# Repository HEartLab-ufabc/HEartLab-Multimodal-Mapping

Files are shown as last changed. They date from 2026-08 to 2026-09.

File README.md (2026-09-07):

# An Open-Source Platform for Multimodal Electrical and Optical Mapping of Ex Vivo Hearts

**A modular research platform for synchronized optical, contact-electrical, and torso-tank mapping of ex vivo perfused hearts.**

> **Repository status:** Active development. Documentation, design files, protocols, and software are being prepared for the first archived release accompanying the associated *Scientific Reports* manuscript.

## Overview

This repository contains the hardware documentation, embedded firmware, experimental-control software, CAD files, representative experimental protocols, and 3D reconstruction tools associated with the HEartLab multimodal mapping platform for ex vivo cardiac electrophysiology.

The platform integrates complementary experimental modalities within a common workflow:

- optical mapping;
- contact electrical mapping using multi-electrode arrays (MEAs);
- torso-tank electrical mapping;
- electrical stimulation;
- physiological monitoring;
- hardware synchronization;
- experiment control and event logging;
- rotational image acquisition and experiment-specific 3D reconstruction.

The system is modular rather than tied to one preparation. Perfusion interfaces, mechanical supports, electrode arrangements, optical geometry, and selected experimental procedures can be adapted according to preparation size, scientific objective, and available equipment.

---

## Experimental configurations

### Small-heart whole-organ configuration

Validated in Langendorff-perfused rabbit hearts. Depending on the experiment, the configuration supports:

- panoramic optical mapping;
- epicardial contact mapping using MEAs;
- torso-tank electrical recordings;
- programmable electrical stimulation;
- physiological monitoring;
- synchronized optical and electrical acquisition;
- experiment control and logging;
- experiment-specific 3D reconstruction.

### Large-heart whole-organ configuration

Validated in porcine and human ex vivo hearts. Depending on the experiment, the configuration supports:

- optical mapping of large cardiac surfaces;
- torso-tank electrical mapping;
- independent coronary perfusion;
- physiological monitoring;
- synchronized acquisition and stimulation;
- mechanical support adapted to larger preparations;
- experiment-specific 3D reconstruction.

### Large-heart epi-endo configuration

Developed for isolated perfused ventricular-wall preparations. Depending on the experiment, the configuration supports:

- simultaneous epicardial and endocardial optical mapping;
- paired epicardial and endocardial contact-electrical mapping;
- mirror-assisted optical access;
- coronary perfusion;
- synchronized stimulation and acquisition;
- physiological monitoring.

The configuration defines the available platform modules, while the **scientific objective determines which modules and protocols are used in a particular experiment**.

---

## Platform modules

HEartLab is organized around interoperable experimental modules:

- **Perfusion** – maintains the isolated preparation under controlled ex vivo conditions.
- **Physiological monitoring** – records perfusion flow, pressure, and temperature.
- **Optical mapping** – records voltage-sensitive fluorescence from cardiac surfaces.
- **Contact electrical mapping** – records local extracellular electrograms using MEAs.
- **Torso-tank mapping** – records cardiac potentials from electrodes surrounding the preparation in a conductive volume.
- **Electrical stimulation** – provides controlled pacing and arrhythmia-induction stimuli.
- **Hardware synchronization** – provides a common timing reference between acquisition systems.
- **Experiment control** – coordinates monitoring, stimulation, synchronization, metadata, and experimental events.
- **3D reconstruction** – combines rotational image acquisition with silhouette-based processing to obtain experiment-specific surface geometry.

---

## Repository structure

```text
HEartLab-Multimodal-Mapping/
├── README.md
├── DISCLAIMER.md
│
├── cad/
│   ├── README.md
│   ├── small_heart/
│   ├── large-heart/
│   └── epi-endo/
│
├── docs/
│   ├── getting_started.md
│   └── protocols/
│
├── firmware/
│   ├── sensors/
│   ├── gateway/
│   ├── stepper_motor_control/
│   └── synchronization_controller/
│
├── hardware/
│   ├── README.md
│   ├── BOM_overview.md
│   ├── perfusion/
│   ├── physiological_monitoring/
│   ├── optical_mapping/
│   ├── electrical_mapping/
│   ├── stimulation/
│   ├── synchronization/
│   ├── mechanical/
│   └── reconstruction_3d/
│
└── software/
    ├── README.md
    ├── experiment_control/
    ├── 3D_reconstruction_capture_labview/
    ├── 3D_reconstruction_capture_python/
    └── 3d_reconstruction_processing/
```

---

## Getting started

A high-level setup and validation workflow is provided in:

**[`docs/getting_started.md`](docs/getting_started.md)**

A typical workflow is:

1. select the experimental configuration;
2. define the scientific objective;
3. select the required platform modules and representative protocols;
4. obtain or fabricate the required hardware;
5. configure firmware and software;
6. validate each subsystem independently;
7. perform an integrated bench test;
8. document the experiment-specific configuration.

The platform does **not** require every subsystem to be used in every experiment.

---

## Experimental protocols

Representative experimental procedures are provided in:

**[`docs/protocols/`](docs/protocols/)**

These documents describe examples of HEartLab implementations rather than universal mandatory procedures. Parameters can vary according to preparation type, species or donor source, heart size, mapping modality, scientific objective, equipment, pharmacological intervention, stimulation protocol, and the applicable approved experimental protocol.

Users are responsible for confirming that concentrations, calculations, settings, and procedures are appropriate for their own experimental implementation.

---

## CAD and mechanical designs

Custom mechanical designs are provided in:

**[`cad/`](cad/)**

The CAD library is organized according to the configuration in which the components were developed:

- [`cad/small_heart/`](cad/small_heart/)
- [`cad/large-heart/`](cad/large-heart/)
- [`cad/epi-endo/`](cad/epi-endo/)

Depending on the component, files include Autodesk Inventor (`.ipt`), Autodesk Fusion (`.f3d` / `.f3z`), STEP/STP, STL, and PDF drawings.

The repository focuses on custom fabricated components. Commercial motors, bearings, pulleys, shafts, fasteners, clamps, and similar off-the-shelf parts are described in the relevant documentation rather than redistributed as proprietary CAD models.

---

## Hardware

Hardware documentation is located in:

**[`hardware/`](hardware/)**

Subsystem documentation includes:

- [`hardware/perfusion/`](hardware/perfusion/) – perfusion and fluidic hardware;
- [`hardware/physiological_monitoring/`](hardware/physiological_monitoring/) – flow, pressure, temperature, sensor nodes, and gateway hardware;
- [`hardware/optical_mapping/`](hardware/optical_mapping/) – cameras, optics, illumination, and mirror-assisted optical access;
- [`hardware/electrical_mapping/`](hardware/electrical_mapping/) – MEAs, small-heart torso-tank hardware, and large-heart tank PCB files;
- [`hardware/stimulation/`](hardware/stimulation/) – experimental constant-current stimulation hardware;
- [`hardware/synchronization/`](hardware/synchronization/) – timing and trigger-distribution hardware;
- [`hardware/mechanical/`](hardware/mechanical/) – assembly-level mechanical documentation linked to the CAD library;
- [`hardware/reconstruction_3d/`](hardware/reconstruction_3d/) – motorized rotational acquisition hardware.

A high-level component inventory is provided in [`hardware/BOM_overview.md`](hardware/BOM_overview.md).

### Large-heart tank PCB

Editable KiCad source, electrode mapping, Gerber/drill outputs, and manufacturing previews are provided under:

**[`hardware/electrical_mapping/large-heart-tank-pcb/`](hardware/electrical_mapping/large-heart-tank-pcb/)**

The large-heart tank uses six PCB faces with 15 electrode pads per face.

---

## Firmware

Embedded firmware is located in:

**[`firmware/`](firmware/)**

The current implementation includes:

- Arduino Nano-based physiological-monitoring sensor nodes;
- nRF24L01 wireless communication;
- an ESP32-S3 sensor gateway;
- a Teensy 4.1 synchronization/stimulation-control interface;
- an Arduino-controlled stepper system for rotational 3D image acquisition.

Subsystem-specific README files describe the associated interfaces and operating assumptions.

---

## Software

Software is located in:

**[`software/`](software/)**

### Experiment control

[`software/experiment_control/`](software/experiment_control/) contains the Python-based application used for experimental session organization, physiological monitoring, stimulation control, synchronization-related operations, metadata, and event logging.

### 3D image acquisition — LabVIEW / EVT

[`software/3D_reconstruction_capture_labview/`](software/3D_reconstruction_capture_labview/) contains the LabVIEW application used with the EVT camera implementation.

The acquisition workflow rotates the preparation at defined angular increments and stores the image sequence used for subsequent 3D reconstruction.

A RHYTHM-derived LabVIEW VI included in this folder retains its original third-party attribution and MIT license notice.

### 3D image acquisition — Python / Imaging Source USB

[`software/3D_reconstruction_capture_python/`](software/3D_reconstruction_capture_python/) contains the Python/OpenCV implementation used with the Imaging Source USB-camera setup.

### 3D reconstruction processing

[`software/3d_reconstruction_processing/`](software/3d_reconstruction_processing/) contains the silhouette-processing and space-carving workflow used to produce experiment-specific surface meshes.

Camera calibration is performed using [MC-Calib](https://github.com/rameau-fr/MC-Calib); its calibration procedure is not duplicated in this repository.

---

## Reproducibility and scope

The repository documents the implementation used to develop and validate the HEartLab platform. Because the platform is modular, exact equipment combinations and experimental procedures can differ among preparations.

For reproducibility, experimental records should preserve the relevant hardware configuration, firmware/software versions, acquisition settings, channel mapping, and protocol parameters used for a given dataset.

Commercial acquisition software, manufacturer drivers, SDKs, and proprietary third-party design files are not redistributed unless their licenses permit redistribution.

---

## Associated manuscript

This repository accompanies:

**Silva, V. P. et al. _An Open-Source Platform for Multimodal Electrical and Optical Mapping of Ex Vivo Hearts_.**

**Status:** manuscript under review.

---

## License

This repository uses a **multi-license structure**:

| Material | License |
|---|---|
| Original software and firmware | MIT License |
| Original hardware and CAD designs | CERN Open Hardware Licence Version 2 – Permissive |
| General documentation and experimental protocols | Creative Commons Attribution 4.0 International |
| Third-party components | Original third-party licenses |

See [`LICENSE.md`](LICENSE.md) for the complete scope and
[`THIRD_PARTY.md`](THIRD_PARTY.md) for third-party exceptions.

---

## Third-party components

Third-party software remains subject to its original license terms.

In particular, the LabVIEW reconstruction-acquisition folder contains a VI derived from the RHYTHM open-source imaging toolkit. Attribution and the applicable MIT license notice are provided in:

[`software/3D_reconstruction_capture_labview/THIRD_PARTY.md`](software/3D_reconstruction_capture_labview/THIRD_PARTY.md)

---

## Contact

For technical questions or reproducibility issues, please open a GitHub issue.

For research collaboration or questions regarding the associated manuscript, contact HEartLab at Universidade Federal do ABC (UFABC).

---

## Disclaimer

The hardware designs, firmware, software, protocols, CAD files, and documentation provided in this repository are supplied **"as is"**, without warranties or guarantees of any kind, either express or implied.

The materials are intended exclusively for experimental research involving ex vivo cardiac preparations. They have not been designed, validated, or approved as medical devices and must not be used for clinical diagnosis, treatment, patient monitoring, or direct use in humans.

Users are responsible for independently reviewing and validating hardware, software, calculations, procedures, electrical connections, experimental parameters, concentrations, and safety measures before use.

The individual researcher or institution conducting an experiment remains responsible for determining whether the platform and associated procedures are appropriate for the intended application and for ensuring compliance with applicable ethical approvals, institutional requirements, laboratory procedures, and safety regulations.

See the complete [`DISCLAIMER.md`](DISCLAIMER.md).

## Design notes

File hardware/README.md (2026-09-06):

# Hardware

This directory contains documentation and design information for the hardware used in the HEartLab multimodal ex vivo cardiac mapping platform.

The platform is modular. A particular experiment does not require every module, and some mechanical, perfusion, optical, and electrical interfaces change according to preparation size and scientific objective.

## Hardware modules

```text
hardware/
├── README.md
├── BOM_overview.md
├── perfusion/
├── physiological_monitoring/
├── optical_mapping/
├── electrical_mapping/
├── stimulation/
├── synchronization/
├── mechanical/
└── reconstruction_3d/
```

### `perfusion/`

Perfusion architecture, reservoirs, pumps, tubing, heat exchange, bubble management, flow monitoring, pressure monitoring, and cannulation interfaces.

### `physiological_monitoring/`

Sensor nodes and gateway hardware used to monitor perfusion flow, pressure, and temperature.

### `optical_mapping/`

Cameras, lenses, excitation illumination, emission filtering, mirror-assisted views, and hardware interfaces used for voltage-sensitive optical mapping.

### `electrical_mapping/`

Contact-electrical mapping and torso-tank mapping hardware, including MEAs, small-heart tank electrodes, large-heart tank PCBs, acquisition interfaces, and channel organization.

### `stimulation/`

Electrical stimulation hardware used for pacing and arrhythmia-induction protocols.

### `synchronization/`

Hardware timing interfaces used to provide a common temporal reference between optical and electrical acquisition systems.

### `mechanical/`

A guide to mechanical hardware and the corresponding CAD repository. Detailed custom mechanical designs are maintained under [`../cad/`](../cad/) rather than duplicated here.

### `reconstruction_3d/`

Motorized rotational hardware and imaging components used to acquire multi-view images for experiment-specific 3D reconstruction.

## Configuration overview

The table below summarizes the typical relationship between hardware modules and the three principal platform configurations.

| Module | Small-heart whole-organ | Large-heart whole-organ | Large-heart epi-endo |
|---|---|---|---|
| Perfusion | Aortic/Langendorff | Independent coronary perfusion | Coronary perfusion |
| Physiological monitoring | Used as required | Used as required | Used as required |
| Optical mapping | Panoramic multi-camera | Large-surface multi-camera | Dual-surface / mirror-assisted |
| Contact electrical mapping | Epicardial MEAs | Experiment dependent | Epicardial + endocardial MEAs |
| Torso-tank mapping | 60-electrode tank implementation | Six-face tank PCB implementation | Not a defining module |
| Electrical stimulation | Experiment dependent | Experiment dependent | Experiment dependent |
| Synchronization | When multimodal acquisition is used | When multimodal acquisition is used | When multimodal acquisition is used |
| 3D reconstruction hardware | Experiment dependent | Experiment dependent | Experiment dependent |

The table describes representative HEartLab implementations and should not be interpreted as a mandatory experimental sequence.

## Design philosophy

The hardware was developed around experimental functions rather than a single fixed physical arrangement.

Common design goals include:

- maintaining controlled perfusion;
- preserving optical and electrical access to the preparation;
- monitoring relevant physiological conditions;
- enabling programmable stimulation where required;
- acquiring complementary electrical and optical measurements;
- providing a common timing reference between acquisition systems;
- allowing adaptation to different preparation dimensions.

## Documentation convention

Each hardware directory contains, where applicable:

- a subsystem overview;
- representative bill of materials;
- configuration-specific notes;
- links to firmware or software;
- links to CAD files;
- fabrication/manufacturing files;
- operating notes, limitations, and compatibility information.

Commercial components are identified to support reproducibility but their proprietary design files are not redistributed.

## Important

The listed hardware corresponds to HEartLab implementations used during platform development. Exact component models, dimensions, calibration, electrical limits, and material compatibility must be independently verified before use.

See the repository-level [`DISCLAIMER.md`](../DISCLAIMER.md).

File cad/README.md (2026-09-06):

# CAD and Mechanical Design Files

This directory contains mechanical design files for custom components used in the HEartLab multimodal mapping platform.

The designs are organized according to the experimental configuration in which they were developed:

- [`small_heart/`](small_heart/) – components used with the small-heart whole-organ configuration;
- [`large-heart/`](large-heart/) – components used with the large-heart whole-organ configuration;
- [`epi-endo/`](epi-endo/) – components used with the large-heart epi-endo configuration.

The majority of the files provided here correspond to **custom components that must be fabricated or 3D printed**.

Commercial and off-the-shelf components, such as motors, bearings, pulleys, belts, shafts, fasteners, clamps, and other standard mechanical components, are identified in the corresponding documentation and assembly drawings but their proprietary CAD models are generally not redistributed in this repository.

## File formats

Where available, components are provided in several formats to facilitate both reproduction and modification.

| Format | Purpose |
|---|---|
| `.ipt` | Native Autodesk Inventor source file |
| `.f3d` | Native Autodesk Fusion design file |
| `.f3z` | Autodesk Fusion archive containing an assembly and/or externally referenced components |
| `.step` / `.stp` | Vendor-neutral CAD exchange format |
| `.stl` | Mesh file intended primarily for additive manufacturing |
| `.pdf` | Assembly drawings, dimensioned drawings, or reference documentation |

Native CAD files are provided whenever possible to preserve design history and editability. STEP files are included to improve compatibility with other CAD software, while STL files are intended primarily for fabrication of 3D-printed components.

## General fabrication notes

The supplied designs correspond to implementations used in HEartLab experiments and should be treated as reference designs rather than universal dimensions.

Mechanical components may require adaptation according to:

- preparation size;
- tank geometry;
- cannula dimensions;
- locally available bearings, shafts, motors, and pulleys;
- camera and electrode positioning;
- available fabrication methods.

Before fabrication, verify:

- model units;
- critical dimensions;
- fit between mating components;
- shaft and bearing tolerances;
- required threaded inserts or fasteners;
- intended material;
- compatibility with the experimental environment.

Components exposed to moisture, perfusate, or corrosive environments should be manufactured using materials and hardware appropriate for those conditions.

## Assemblies and off-the-shelf components

Assembly drawings may show commercial components that are not included as CAD files in this repository.

This is intentional. Their presence in an assembly is intended to document the mechanical interface and reproduce the experimental arrangement, not to redistribute manufacturer designs.

Relevant specifications for these components are listed in the corresponding README or bill of materials.

## Configuration-specific documentation

Each configuration directory contains additional information describing:

- the purpose of each custom component;
- required quantities;
- associated commercial components;
- assembly considerations;
- fabrication recommendations;
- files available for each part.

## Modification and reuse

The mechanical system is intentionally modular. Users may modify the designs to accommodate different preparations, tanks, equipment, or experimental objectives.

Any modified design should be mechanically verified before experimental use.

See the repository-level `DISCLAIMER.md` for additional information regarding validation, responsibility, and intended use.

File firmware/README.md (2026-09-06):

# Embedded Firmware

This directory contains firmware used by the embedded control, monitoring, synchronization, and motor-control subsystems of the HEartLab multimodal mapping platform.

## Directory structure

### `sensors/`

Firmware for Arduino Nano-based physiological-monitoring nodes.

### `gateway/`

Firmware for the ESP32-S3 gateway that receives physiological-monitoring data and interfaces with the experimental-control computer.

### `synchronization_controller/`

Firmware for the Teensy 4.1 timing controller used to generate and distribute experimental synchronization signals.

### `stepper_motor_control/`

Arduino firmware for the motorized rotational stage used during experiment-specific 3D reconstruction image acquisition.

The controller receives angular movement commands through the serial interface and drives a STEP/DIR stepper-motor driver.

A representative reconstruction acquisition uses approximately 100 positions over 360°, corresponding to 3.6° increments.

See:

[`stepper_motor_control/README.md`](stepper_motor_control/README.md)

## Monitoring and synchronization architecture

```text
Sensor node 1 --\
                 \
Sensor node 2 ----> wireless --> ESP32-S3 gateway --> USB --> Experiment computer
                 /
Additional ------/
nodes

Experiment computer --> timing/synchronization controller --> acquisition systems
```

Refer to the subsystem-specific README files for exact interfaces.

## Rotational image-acquisition architecture

```text
Image-acquisition software
        |
        | Serial/USB
        v
     Arduino
        |
    STEP / DIR
        v
 Stepper driver
        |
        v
 Stepper motor
        |
        v
Rotational support
```

The current LabVIEW image-acquisition implementation is designed for EVT cameras:

[`../software/3D_reconstruction_capture_labview/`](../software/3D_reconstruction_capture_labview/)

The Python/OpenCV acquisition implementation for the Imaging Source USB-camera setup is available at:

[`../software/3D_reconstruction_capture_python/`](../software/3D_reconstruction_capture_python/)

## Development environment

Controller, library, pin-assignment, communication, and upload information is provided in the subsystem-specific README files together with the corresponding source code.

## Disclaimer

Firmware in this repository is provided for experimental research and must be independently verified with the intended electronics and mechanical system before experimental use.

See the repository-level [`DISCLAIMER.md`](../DISCLAIMER.md).

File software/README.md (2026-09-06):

# Software

This directory contains software developed or used to support operation of the HEartLab multimodal mapping platform.

The current repository includes software for:

- experiment control and logging;
- rotational image acquisition using the EVT camera system;
- rotational image acquisition using the Imaging Source USB camera.

## Directory structure

```text
software/
├── experiment_control/
├── 3d_reconstruction_capture_labview/
└── 3d_reconstruction_capture_python/
```

## Experimental control

[`experiment_control/`](experiment_control/) contains the Python-based graphical application used to coordinate several experimental functions, including:

- experimental session organization;
- physiological monitoring;
- stimulation control;
- synchronization-related operations;
- recording coordination;
- metadata entry;
- event logging.

The application acts as an integration and control layer and does not replace every manufacturer-supplied acquisition application used by the platform.

## 3D reconstruction image acquisition — LabVIEW / EVT

[`3d_reconstruction_capture_labview/`](3d_reconstruction_capture_labview/) contains the LabVIEW application used to automate rotational image acquisition with the EVT camera system used in HEartLab.

A representative acquisition captures approximately 100 views over a complete 360° rotation.

The application is configured around the EVT acquisition interface and should not be expected to work directly with cameras from other manufacturers without modification.

The folder also contains `saveNumberedImages.vi`, originally obtained from the RHYTHM open-source imaging toolkit and redistributed under its applicable MIT License. See the folder README and the repository-level `THIRD_PARTY.md`.

## 3D reconstruction image acquisition — Python / Imaging Source USB

[`3d_reconstruction_capture_python/`](3d_reconstruction_capture_python/) contains the Python/OpenCV application used with the Imaging Source USB camera in HEartLab.

The application:

- accesses the camera through OpenCV;
- provides a preview for camera adjustment;
- captures numbered TIFF images;
- sends incremental rotation commands to the Arduino rotational controller;
- waits for completion of each motor movement;
- acquires the requested number of unique angular views.

The standard 100-image workflow uses 3.6° increments.

Other OpenCV-accessible cameras may work, but compatibility and camera-property behavior must be independently verified.

## Shared rotational-stage firmware

Both image-acquisition implementations use the motorized rotational stage documented in:

[`../firmware/stepper_motor_control/`](../firmware/stepper_motor_control/)

when configured with compatible serial communication.

## Reconstruction versus image acquisition

The software in these two folders performs **multi-view image acquisition** for 3D reconstruction.

Subsequent processing stages such as:

- camera calibration;
- silhouette segmentation;
- space carving;
- volume reconstruction;
- surface-mesh generation;
- mesh processing;

are separate from the acquisition programs and should be documented independently where the corresponding code or procedures are available.

## 3D reconstruction processing

[`3d_reconstruction_processing/`](3d_reconstruction_processing/) contains the Python workflow used to process rotational image sequences into experiment-specific surface models.

The canonical processing path is:

```text
MC-Calib camera calibration
        ↓
rotational images
        ↓
undistortion
        ↓
silhouette extraction / correction
        ↓
rotational space carving
        ↓
voxel visual hull
        ↓
triangular surface mesh
```

Camera-calibration instructions are not duplicated in this repository. Users should follow the upstream [MC-Calib](https://github.com/rameau-fr/MC-Calib) documentation and provide its camera-parameter YAML output to the HEartLab reconstruction program.

The reconstruction folder also contains an optional PCA-based silhouette-alignment utility. 

## External software and drivers

The platform also uses manufacturer-supplied or third-party software, drivers, and SDKs.

These are not redistributed unless their licenses explicitly allow redistribution.

Users should consult the respective developer or manufacturer for installation and licensing requirements.

## Reproducibility

Each software component should document:

- tested operating system;
- tested language/runtime version;
- required dependencies;
- hardware interfaces;
- communication settings;
- expected inputs and outputs;
- known compatibility limitations.

For published work, use the tagged repository release associated with the publication whenever possible.

## Disclaimer

Software in this repository is provided for experimental research and must be independently verified for the intended hardware and application.

See the repository-level [`DISCLAIMER.md`](../DISCLAIMER.md).

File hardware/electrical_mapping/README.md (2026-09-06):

# Electrical Mapping Hardware

This directory documents the contact-electrical and torso-tank mapping hardware used by the HEartLab platform.

The electrical subsystem includes:

- epicardial/endocardial multi-electrode arrays (MEAs);
- small-heart torso-tank electrodes;
- large-heart tank electrode PCBs;
- acquisition hardware and interconnection;
- reference/ground arrangements;
- configuration-specific channel mapping.

## Directory structure

```text
electrical_mapping/
├── README.md
├── BOM.md
├── contact_meas/
├── small-heart-torso-tank/
└── large-heart-tank-pcb/
```

## Acquisition

The platform implementation uses an [`Intan RHD Recording System`](https://www.intantech.com/RHD_system.html) or an [`Open Ephys`](https://open-ephys.org/) acquisition chain for electrical recordings.

The headstages used were [`Intan RHD 64-Channel Recording Headstages`](https://www.intantech.com/RHD_headstages.html?tabSelect=RHD64ch&yPos=0), the number of headstages used were dependent on which modality was being recorded and the number of recording channels.

Verify with the manufacturer all the necessary equipment for your specific application. 

## Contact electrical mapping

See:

[`contact_meas/`](contact_meas/)

Small-heart experiments use three 16-electrode epicardial MEAs positioned over right atrial, left atrial, and ventricular regions.

The epi-endo configuration uses paired epicardial and endocardial contact arrays.

## Small-heart torso-tank mapping

See:

[`small-heart-torso-tank/`](small-heart-torso-tank/)

The hexagonal small-heart tank contains 60 electrodes, with 10 electrodes distributed on each of six faces.

## Large-heart torso-tank mapping

See:

[`large-heart-tank-pcb/`](large-heart-tank-pcb/)

The large-heart tank uses six custom electrode PCBs. Each PCB contains 15 electrode pads, giving 90 bath-potential electrodes when all six faces are populated.

## Terminology

Repository documentation uses **torso-tank mapping** for electrical recordings from the conductive volume surrounding the preparation.

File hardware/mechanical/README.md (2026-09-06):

# Mechanical Hardware

Detailed custom mechanical designs are maintained in the repository's [`cad/`](../../cad/) directory.

This hardware directory is intentionally not a second copy of the CAD library.

## CAD organization

```text
cad/
├── small-heart/
├── large-heart/
└── epi-endo/
```

The CAD library includes custom components such as:

- small-heart cannula and support system;
- small-heart serpentine support;
- large-heart heart support;
- large-heart motorized main support;
- large-heart transparent-PCB support;
- epi-endo main support;
- epi-endo mirror holder.

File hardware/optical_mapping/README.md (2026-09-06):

# Optical Mapping Hardware

This directory documents the hardware used for voltage-sensitive optical mapping.

The optical arrangement changes with preparation geometry while retaining the same main functions:

- illuminate the preparation at the required excitation wavelength;
- collect fluorescence from one or more cardiac surfaces;
- spectrally isolate the emitted fluorescence;
- acquire images at high temporal resolution;
- synchronize image acquisition with electrical recordings.

## Optical components

The HEartLab implementations described in the associated work use:

- high-speed optical cameras;
- approximately 25 mm lenses;
- approximately 650 nm excitation LEDs;
- approximately 715 nm long-pass emission filters;
- camera and illumination supports;
- a 45° mirror in the epi-endo implementation.

Acquisition settings used in the platform include 500 frames/s, 1600 × 1000 pixels, and 12-bit acquisition where supported by the camera configuration.

These values describe the optical-mapping acquisition used in the platform implementation.

## Configuration-specific arrangements

### Small-heart whole-organ

The panoramic arrangement uses three cameras distributed around the preparation, approximately 120° apart, together with multiple excitation LEDs.

### Large-heart whole-organ

The large-heart arrangement uses two camera views to increase surface coverage.

### Large-heart epi-endo

The epi-endo implementation uses two optical cameras and a 45° mirror to provide complementary access to epicardial and endocardial surfaces.

The custom mirror holder is documented under:

[`../../cad/epi-endo/`](../../cad/epi-endo/)

## Synchronization

Camera acquisition is synchronized with the electrical acquisition system using the timing hardware described in:

[`../synchronization/`](../synchronization/)

## Camera models

The EVT and Imaging Source cameras documented under the 3D-reconstruction software are reconstruction/image-capture implementations and should not automatically be assumed to be the same cameras used for high-speed optical mapping.

## Reagents

Voltage-sensitive dye and motion-suppression can be found at:

[`../../docs/protocols/`](../../docs/protocols/)

See [`BOM.md`](BOM.md) for the current optical hardware list.

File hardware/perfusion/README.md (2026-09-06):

# Perfusion Hardware

This directory documents the perfusion hardware used to maintain the ex vivo cardiac preparations.

The platform uses a shared perfusion concept that is adapted to the preparation rather than three completely independent systems.

## Common instrumented perfusion line

A perfusion line contains:

- perfusate reservoir(s);
- pump and/or hydrostatic pressure source;
- analog flow indication;
- heat exchange;
- bubble management;
- digital flow and inline temperature sensing;
- pressure sensing close to the preparation;
- tubing and connectors;
- carbogen gas source;
- preparation-specific cannulation interface.

The exact order and placement of these elements should follow the validated configuration schematic for the experiment.

## Configuration-specific interfaces

### Small-heart whole-organ

The small-heart implementation uses an aortic/Langendorff cannulation interface.

The custom rotating cannula assembly is documented under:

[`../../cad/small_heart/cannula/`](../../cad/small_heart/cannula/)

The serpentine support is documented under:

[`../../cad/small_heart/serpentine_support/`](../../cad/small_heart/serpentine_support/)

### Large-heart whole-organ

The large-heart whole-organ configuration uses independent coronary perfusion lines.

The common reservoir/pump architecture can feed two instrumented lines, each with its own monitoring chain, before connection to the appropriate coronary cannulation interface.

### Large-heart epi-endo

The epi-endo preparation uses a coronary perfusion line connected to the isolated tissue preparation.

The epi-endo mechanical support constrains the perfusion tubing to reduce mechanical loading of the tissue:

[`../../cad/epi-endo/`](../../cad/epi-endo/)

## Physiological monitoring

The digital flow, temperature, and pressure sensors are documented in:

[`../physiological_monitoring/`](../physiological_monitoring/)

## Experimental parameters

Perfusion pressure, flow, temperature, solution composition, and total solution volume are experimental parameters rather than fixed hardware specifications.

Protocol values are therefore documented under:

[`../../docs/protocols/`](../../docs/protocols/)

## Verification before use

Before connection to a cardiac preparation:

- leak-test the complete fluidic path;
- verify cannula and connector retention;
- verify bubble-trap operation;
- verify unobstructed tubing;
- verify flow-sensor and pressure-sensor readings;
- verify the pressure measurement near the preparation;
- verify temperature under flow;
- inspect all components that contact perfusate;
- ensure materials are compatible with the intended solution and temperature.

See [`BOM.md`](BOM.md) for the current hardware list.

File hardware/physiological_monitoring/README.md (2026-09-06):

# Physiological Monitoring Hardware

This subsystem monitors perfusion conditions and forwards them to the experiment-control computer.

The current implementation uses independent sensor nodes for active perfusion lines and a central ESP32-S3 gateway.

## Architecture

```text
Perfusion line
    │
    ├── flow + inline temperature sensor
    ├── pressure sensor
    └── optional/local temperature measurement
             │
             ▼
        Arduino Nano
             │
          nRF24L01
             │
             ▼
       ESP32-S3 gateway
             │
            USB
             │
             ▼
   Experiment-control computer
```

## Sensor node

The current sensor-node implementation uses:

- Arduino Nano;
- Sensirion SLF3S-4000B flow/temperature sensor;
- Honeywell digital pressure sensor;
- nRF24L01 wireless transceiver.

One sensor node can be associated with each instrumented perfusion line.

The corresponding firmware is available at:

[`../../firmware/sensors/`](../../firmware/sensors/)

## Gateway

The gateway implementation uses:

- ESP32-S3 development board;
- nRF24L01 wireless transceiver;
- USB serial connection to the experiment computer.

Firmware:

[`../../firmware/gateway/`](../../firmware/gateway/)

## Flow sensor

The current firmware identifies the flow sensor as:

**Sensirion SLF3S-4000B**

The implementation also reads the fluid-temperature value reported by the flow sensor.

## Additional temperature monitoring

HEartLab experiments have also used a tank/chamber temperature measurement based on a K-type thermocouple implementation.

Tank/chamber temperature is measured with a K-type thermocouple implementation using a MAX31855 interface module.

## Adaptation

The Arduino Nano is not a fundamental requirement of the platform.

Other microcontrollers can be used if they provide compatible sensor interfaces and preserve the required data path to the experiment-control software.

See [`BOM.md`](BOM.md).

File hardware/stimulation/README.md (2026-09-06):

# Electrical Stimulation Hardware

This directory documents the stimulation hardware associated with the platform implementation described in the paper.

## Validated paper-associated implementation

The stimulator is a single-channel constant-current design based on a PNP current-mirror architecture.

Characteristics include:

- approximately 100 µA to 45 mA adjustable current range;
- four 9 V batteries in series as the isolated high-voltage supply;
- approximately 42 V practical compliance in the implementation;
- isolated trigger input;
- 2 ms pacing pulse duration.

The pulse duration and stimulation protocol are experiment parameters and are controlled through the corresponding stimulation/control software.

## Intended use

The stimulator is used for experimental procedures such as:

- capture testing;
- regular pacing;
- S1–S2 pacing;
- burst pacing;
- arrhythmia-induction protocols.

## Repository contents

This directory provides an architecture-level description and component summary of the experimentally validated single-channel current-mirror stimulator.

## Required verification

Before connection to a biological preparation:

- verify output current into representative loads;
- verify pulse duration;
- verify compliance behavior;
- verify startup/reset behavior;
- verify battery condition;

> [!WARNING]
> This stimulation hardware is intended exclusively for experimental ex vivo research. Verify output amplitude, timing, polarity, isolation, and startup behavior using appropriate test equipment and a representative load before connection to a biological preparation.

See [`BOM.md`](BOM.md) and the repository-level `DISCLAIMER.md`.

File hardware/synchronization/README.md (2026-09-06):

# Synchronization Hardware

This subsystem provides a common timing reference between otherwise independent acquisition systems.

## Current implementation

The current synchronization-controller firmware is associated with a **Teensy 4.1** controller.

Firmware:

[`../../firmware/synchronization_controller/`](../../firmware/synchronization_controller/)

The implementation distributes a 500 Hz TTL-level timing signal to:

- optical camera timing/trigger interfaces;
- the digital input of the Open Ephys electrical acquisition system.

This shared timing signal allows optical and electrical recordings to be aligned during analysis.

## Architecture

```text
Experiment-control computer
            │
            ▼
    Teensy 4.1 controller
            │
       timing output
        ┌───┴───────────┐
        ▼               ▼
 Optical cameras   Open Ephys digital input
```

The experiment-control computer communicates with the timing controller using the serial command interface implemented in the synchronization firmware.

## Electrical interface

> [!CAUTION]
> Do not assume that every camera accepts the same trigger voltage or termination.

Before connecting synchronization hardware, verify:

- controller output voltage;
- camera trigger-input voltage limits;
- electrical acquisition digital-input limits;
- required polarity;
- grounding;
- cable termination;
- edge timing.

See [`BOM.md`](BOM.md).

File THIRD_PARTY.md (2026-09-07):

# Third-Party Software and Materials

Third-party material included in or referenced by this repository remains
subject to its original copyright and license terms. The licenses applied to
original HEartLab material do not override third-party licenses.

## RHYTHM open-source imaging toolkit

**Included component**

`software/3D_reconstruction_capture_labview/saveNumberedImage.vi`

This VI was obtained from the RHYTHM open-source imaging toolkit and is used
within the HEartLab LabVIEW rotational image-acquisition workflow.

**Original project**

RHYTHM — *An Open Source Imaging Toolkit for Cardiac Panoramic Optical
Mapping*

**License**

MIT License

**Original copyright notice**

Copyright (c) 2018 optocardiography

The applicable license notice and detailed attribution are preserved in:

- `software/3D_reconstruction_capture_labview/RHYTHM_LICENSE.txt`
- `software/3D_reconstruction_capture_labview/THIRD_PARTY.md`

## External software and dependencies

The repository also references or depends on third-party software, libraries,
drivers, SDKs, and commercial applications. Examples include Python packages,
Arduino/embedded libraries, LabVIEW, camera drivers/SDKs, Open Ephys, and CAD
software.

Unless a third-party component is actually redistributed in this repository,
its license text is not duplicated here. Users must obtain those components
from their respective authors, developers, or manufacturers and comply with
the applicable terms.

## Manufacturer and commercial material

Product names and manufacturers may be identified to support reproducibility.
Such references do not imply ownership by HEartLab, endorsement by the
manufacturer, or permission to redistribute proprietary documentation,
drivers, CAD, trademarks, or other protected material.

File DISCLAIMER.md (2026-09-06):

# Disclaimer

## Research use only

The hardware designs, firmware, software, experimental protocols, mechanical designs, data formats, diagrams, and other documentation provided through the HEartLab Multimodal Mapping repository are intended solely for scientific and experimental research involving ex vivo cardiac preparations.

The platform is not a medical device and has not been designed, certified, validated, or approved for clinical diagnosis, treatment, patient monitoring, life support, or direct use in humans.

## Provided "as is"

All materials in this repository are provided **"as is"** and **"as available"**, without warranties or guarantees of any kind, whether express, implied, statutory, or otherwise.

No guarantee is made regarding, including but not limited to:

- correctness;
- completeness;
- accuracy;
- reliability;
- fitness for a particular purpose;
- compatibility with other equipment;
- reproducibility under different experimental conditions;
- absence of errors or omissions;
- continued availability or maintenance.

Repository contents may change as the platform is developed and additional experimental configurations are validated.

## User responsibility

Users are solely responsible for independently evaluating whether the materials provided in this repository are appropriate for their intended application.

Before experimental use, users should independently verify, as applicable:

- electrical connections and voltage/current limits;
- stimulation output and timing;
- hardware synchronization;
- sensor calibration and scaling;
- firmware and software configuration;
- mechanical integrity;
- perfusion-system operation;
- pressure, flow, and temperature measurements;
- solution compositions and calculations;
- pharmacological concentrations and dosing calculations;
- acquisition parameters;
- data-storage and backup procedures;
- biological and chemical safety requirements.

A procedure, parameter, component, or configuration documented in this repository should not be assumed to be suitable for a different experimental preparation or scientific objective without appropriate verification.

The individual researcher or institution conducting the experiment remains responsible for the design, execution, supervision, validation, and interpretation of the experiment.

## Experimental protocols

Experimental protocols included in this repository document procedures used in selected HEartLab experiments.

They should not be interpreted as universal protocols or as a substitute for scientific judgment.

Experimental conditions may vary according to:

- preparation;
- species;
- experimental objective;
- mapping modalities;
- hardware configuration;
- pharmacological intervention;
- institutional requirements;
- ethical approval.

Users are responsible for confirming all concentrations, calculations, timings, equipment settings, and procedural details before use.

## Ethical and regulatory responsibility

Users are responsible for obtaining and complying with all approvals and requirements applicable to their work, including, where relevant:

- institutional animal-use approval;
- human-tissue or donor-tissue approval;
- biosafety requirements;
- chemical-safety requirements;
- electrical-safety requirements;
- institutional laboratory procedures;
- applicable local laws and regulations.

Nothing in this repository constitutes authorization to conduct any experimental procedure.

## Third-party equipment and software

References to commercial hardware, third-party software, manufacturers, or specific products are provided for documentation and reproducibility purposes.

HEartLab and UFABC do not warrant or guarantee the performance, suitability, safety, availability, or compatibility of third-party products.

Users should consult the corresponding manufacturer or developer documentation before use.

## Limitation of liability

To the maximum extent permitted by applicable law, HEartLab, Universidade Federal do ABC (UFABC), the authors, maintainers, contributors, and affiliated institutions shall not be liable for any direct, indirect, incidental, special, consequential, or other damages or losses arising from the use, inability to use, misuse, modification, or interpretation of materials provided in this repository.

This includes, without limitation:

- experimental failure;
- equipment damage;
- loss or corruption of data;
- incorrect experimental results;
- loss of research time or resources;
- biological injury;
- electrical injury;
- property damage;
- consequences resulting from incorrect implementation or interpretation of the documentation.

Users assume responsibility for evaluating and managing the risks associated with their implementation.

## Licensing

This disclaimer supplements, but does not replace, the warranty and liability provisions of the licenses applicable to individual materials in this repository.

If any provision of this disclaimer conflicts with the applicable license, the terms of the applicable license govern.

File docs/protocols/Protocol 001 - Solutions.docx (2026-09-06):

Protocol 001: Solutions

HEartLab, 2026
Guide to reagents and concentrations for preparing solutions.

Solution preparation

● In distilled water, mix the quantities listed in the table according to the required final volume.
Important: CaCl₂ must be dissolved separately to avoid precipitation.

● Filter the solution using filter paper (specify the type or pore size if needed).

● With the Langendorff Setup, put the complete solution in the reservoir and flow carbogen through it for at least 10 minutes, let it flow at a rate of 30mL/min, and after 3 minutes, collect 30mL of solution in a 50mL beaker. Measure the pH immediately if the pH is not around 7.4 or less. Correct the solution with 1mL of 0.1M of HCl for every 1L of solution and repeat the process.

Modified Krebs–Henseleit solution (General purpose)

| Con. (mMol/L) | Molar mass (g/Mol) | g/0.5 L | g/1 L | g/2 L | g/4 L | g/10 L | g/12L
NaCl | 115 | 58.44 | 3.3603 | 6.7206 | 13.4412 | 26.8824 | 67.2060 | 80.6472
KCl | 4.6 | 74.55 | 0.1715 | 0.3429 | 0.6859 | 1.3717 | 3.4293 | 4.1152
NaHCO3 | 25 | 84.01 | 1.0501 | 2.1003 | 4.2005 | 8.4010 | 21.0025 | 25.2030
CaCl2 . 2H2O | 1.2 | 147.02 | 0.0882 | 0.1764 | 0.3528 | 0.7057 | 1.7642 | 2.1171
KH2PO4 | 1.2 | 136.09 | 0.0817 | 0.1633 | 0.3266 | 0.6532 | 1.6331 | 1.9597
MgSO4 . 7H2O | 1.2 | 246.48 | 0.1479 | 0.2958 | 0.5916 | 1.1831 | 2.9578 | 3.5493
NaPyruvate | 1 | 110 | 0.0550 | 0.1100 | 0.2200 | 0.4400 | 1.1000 | 1.3200
Glucose | 11 | 180.16 | 0.9909 | 1.9818 | 3.9635 | 7.9270 | 19.8176 | 23.7811

Cardioplegia

Reagents | Molar Mass (g/mol) | Molarity (M) | g/L | g/ 0.5L
NaCl | 58.44 | 0.11 | 6.43 | 3.215
KCl | 74.55 | 0.016 | 1.19 | 0.595
NaHCO3 | 84 | 0.01 | 0.84 | 0.42
MgCl2.6H2O | 203.33 | 0.16 | 32.5 | 16.25
CaCl2.2H2O | 147.02 | 0.0012 | 0.176 | 0.088

Sucrose Electrolytic Solution

Reagents | Molar Mass (g/mol) | Molarity (M) | g/L | g/4L | g/2L
NaCl | 58.44 | 0.023 | 1.3441 | 5.3764 | 2.6882
Sucrose (Sacarose) | 342.3 | 0.26 | 88.998 | 355.992 | 177.996
Target Conductivity | | 500Ωcm = 2mS/cm

Special Reagents

Carbachol Stock (1mM)

- Molar Mass: 182.7 g/mol.
- For 1 mM: 0.183 mg/ml.
- Prepare 20 ml and distribute into 20 Eppendorf tubes with 1 ml each.
- Dissolve 3.66 mg in 20 ml of water.
- The working solution is 1 µM.
- Dilute 1 ml (1 Eppendorf) in 999 ml of nutrient solution.

Dye (0.25 mg per Eppendorf)

- Follow Dye Protocol

Blebbistatin (1 mg per Eppendorf)

- 1 Eppendorf contains:
- 1 mg of (-)-Blebbistatin or (+-)-Blebbistatin
- 200 µl of DMSO.

HEartLab group Version 04

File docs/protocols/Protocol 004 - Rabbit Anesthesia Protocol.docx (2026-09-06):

# Protocol 004: Euthanasia

Date of Experiment: _________________________

Animal’s weight: _________________________ Sex: ___________________

Heart’s weight: _____________________ Dimensions: ______________

Volume Syringe 1: ____________________ Hour:____________________

Volume Syringe 2: ____________________ Hour:____________________

Euthanasia Time: _______________________

Rabbit Age: _______________________

# Syringe Preparation

1. Syringe 01: Ketamine and Xylazine
  a. Dosage
      1. Ketamine = 50 mg/Kg
      2. Xylazine = 7 mg/Kg
2. Syringe 02: Heparin
  a. Dosage = 500 U/Kg

# Calculations

Volume(ml)= (weight (Kg)*Dosage ((mg)/(Kg)))/(Concentration((mg)/(ml)))

Volume Syringe 01 (Ketamine) (ml)= ()/()

Volume Syringe 01 (Xylazine) (ml)= ()/()

Volume Syringe 01 (Xylazine+Ketamine)= _________________________________

Volume Seringa 02 (Heparin) (ml)= ()/()

Extra dose. Details: ______________________________________________________

______________________________________________Hour:______________________

# Chemical Procedure

Mix Ketamine and Xylazine in a Falcon tube before administration.

Administer Syringe 01 (Ketamine and Xylazine), by injecting Intramuscularly half the dose into one hind leg and the other half into the opposite hind leg.

Wait 10 minutes.

Administer Syringe 02 (Heparin) via intravenous into an ear vein.

Wait 10 minutes.

Confirm an adequate depth of anesthesia according to the approved animal-use protocol before beginning any invasive terminal procedure.

Proceed with the euthanasia procedure.

# Euthanasia and heart extraction

Open the thorax through a horizontal incision at the apex of the sternum. Then, make a vertical incision from the sternal apex toward the base of the neck.

Open (or break) the pericardium.

Identify the aorta, clamp its distal portion, and carefully cut around all surrounding pulmonary tissue. Finally, cut the aorta.
Important: Hold the aorta firmly to avoid losing it.

Immediately insert a syringe containing oxygenated and 37 degrees Krebs solution into the aorta and perfuse until the outflow appears clear and free of blood.

Jimena Gabriela Paredes; Tainan Neves Version 06

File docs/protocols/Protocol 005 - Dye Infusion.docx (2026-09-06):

# Protocol 005: Dye Infusion

HEartLab, 2025
Infusion of the Dye (Di-4-ANBDQPQ) for Langendorff isolated rabbit heart

# Procedure

1. Once the heart is appropriately accommodated to the perfusion for about 15 minutes, the dye can be added.
2. Dissolve one Eppendorf tube containing 0.25 mg of the dye into the 50 ml of Nutrient Solution heated at 38°C in a Becker. Regarding heating the nutrient solution, it will work equally well if you heat it to 30°C or keep it at room temperature.
3. Turn off the peristaltic pump that fills the upper flask reservoir.
4. Then, the dye, which has been dissolved, is added to the upper flask reservoir from the Langendorff system, which is filled up to approximately 100 mL or more.
5. Use a beaker to collect the perfusate and reuse it for infusion.
  a. Reuse until the solution is clear, generally 1 or 2 times.
  b. Remember to filter the solution in the vacuum pump before reperfusing it.
6. The perfusion can then continue until the upper flask reservoir is empty.
7. Turn back the peristaltic pump and continue to perfuse the regular perfusion solution.

# Observations

1. To ensure optimal distribution of the dye throughout the heart, it is recommended to maintain a controlled flow rate. It is advised not to exceed a flow rate of 20 ml/min, allowing the dye to slowly reach all regions of the heart. In that manner, it will take 5 to 10 minutes until the 250 ml empties.
2. For each rabbit heart, an Eppendorf tube containing 0.25mg of the dye is typically used, which is more than enough for the procedure. In a recent experiment, we successfully utilized only 0.75mg of the dye for an entire human heart, whereas the usual dosage is 2mg.

Dr. Ilija Uzelac; Tainan C. Neves Version 02

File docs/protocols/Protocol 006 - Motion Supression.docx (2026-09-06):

# Protocol 006: Heart Movement Blockage

HEartLab, 2025
Blockage of the movement of the heart due to its contractility

# Procedure

1. Each Eppendorf tube contains 1mg of (+)-Blebbistatin (MM = 305.38 g/mol). Blebbistatin concentration in the nutrient solution is recommended at least 1,7 uM (approximately 1mg of Blebbistatin for 2 litres of the nutrient solution).
  a. Obs1: In some cases, 1.7uM may not be sufficient, and it may be necessary to increase the concentration.
  b. Obs2: Avoid dissolving Blebbistatin at room temperature.
  c. Obs3: The temperature of the tubes containing Blebbistatin, and the small nutrient solution volume should be close to each other.
  d. Obs4: The best is to have the Eppendorf with (+)-Blebbistatin floating inside a beaker glass filled with water, heated by a heating plate, and in the same plate the 50 to 100 ml of Tyrode volume is also heated, in the same temperature.
2. To prepare the Blebbistatin, pour the content of the tube into a 30°C heated 50 ml of nutrient solution. It will generate a 66 μM Solution.
3. After dissolving check that the colour of the solution is transparent.
4. Add the Blebbistatin to the perfusate as follows:
  a. For initial motion suppression, add 25 ml of concentrated solution (66 uM) containing dissolved Blebbistatin to the upper flask reservoir, containing 25-75 (50) ml of nutrient solution, in the Langendorff setup.
    i. This will result in an initial concentration of approximately 22 μM. If the flask is filled with 50 ml of nutrient solution.
  b. Mix the remaining solution containing 25 ml of Concentrated Blebbistatin (66 uM) to the main nutrient solution 1L reservoir. This way the final Blebbistatin concentration is 1.7 uM.

# Observations

1. A higher temperature of around 40°C works better but can be more challenging and result in precipitates from the nutrient solution. If the temperature is too low, Blebbistatin may precipitate.
2. Please check the heart, and also throughout the cameras, if there is any mechanical movement. If everything goes well, the high concentration will cease heart concentration as soon as the Blebbistatin reaches the heart, and the low concentration nutrient solution will maintain the steady state. Usually, high concentration works well, and the effect is fast. During the experiment, if the heart starts to contract it is an indicator that a higher than 1.7 uM Blebbistatin concentration is needed and usually another high concentration infusion of Blebbistatin is needed.
3. PS: If you use (±)-Blebbistatin, it will be necessary to double the concentration.

Dr. Ilija Uzelac; Tainan C. Neves Version 01

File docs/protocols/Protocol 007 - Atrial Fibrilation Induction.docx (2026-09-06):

# Protocol 007: Atrial Fibrillation induction

HEartLab, 2025
Atrial Fibrillation induction

# Procedure

1. Elute 1ml of a 1mM Carbachol solution (1 Eppendorf) in 999 ml of nutrient solution. This will generate a 1uM solution of Carbachol (use solution).
  a. In the case of using an Acetylcholine solution, the procedure is the same.
    i. Elute 1ml of a 1mM acetylcholine solution (1 Eppendorf) in a 999ml of nutrient solution. This will generate a 1uM solution of acetylcholine (use solution).
2. Elute 25 ml of Concentrated Blebbistatin (66 uM at 30°C) to that 1L solution.
  a. Following almost the same protocol for “Heart movement blockage”.
    i. (+)-Blebbistatin = 0.5 Eppendorf
    ii. (±)-Blebbistatin = 1.0 Eppendorf
3. Turn off the peristaltic pump.
4. Wait for a low volume in the upper flask reservoir.
5. Infuse the eluted 1uM carbachol solution into the heart using the solution input of the Langendorff system.
6. Wait for up to 30 seconds.
7. Before the electrical stimulation, we need to see a consistent decrease in the heart rate rhythm.
8. Proceed with the electrical pacing protocol described below.
  a. Burst Protocol
    i. Duration: 2s each burst
    ii. Pulse Width: 2ms
    iii. Cycle Length: 20ms (50Hz)
    iv. Number of Bursts: 8
    v. Interval between Bursts: 10s
  b. Wait ten minutes between each protocol
  c. Repeat a maximum of 5 times.
9. If the initial induction sequence is unsuccessful, an alternative experiment-specific induction sequence may be applied. The complete parameters of any alternative sequence must be recorded in the experiment log.
10. Make all the recordings in the AF situation.
11. Stops the administration of the Carbachol solution when the AF recording ends.
  a. Back to a default nutrient solution.

# Reference

Zafalon Jr N, Bassani JWM, Bassani RA. Cholinergic–adrenergic antagonism in the induction of tachyarrhythmia by electrical stimulation in isolated rat atria. Journal of Molecular and Cellular Cardiology 37 (2004) 127–135.

In this version the protocol of pacing has been adapted from the above article, to rabbit’s atria heart.

Dr João Salinet; Jimena Gabriela Paredes; Tainan Neves Version 03

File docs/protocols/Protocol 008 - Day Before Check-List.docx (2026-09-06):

Protocol 008: Pre-experiment Checklist

- Production of distilled water
  - ____________________________________________________________
- Sterilize surgical materials
  - ____________________________________________________________
- Langendorff cleaning with alcohol.
  - ____________________________________________________________
- Langendorff cleaning with Distilled water.
  - ____________________________________________________________
- Clean Recirculation System.
  - ____________________________________________________________
- Charge the Batteries of the LED lights.
  - ____________________________________________________________
- Check temperature control.
  - ____________________________________________________________
- Check cameras.
  - ____________________________________________________________
- Check LEDs.
  - ____________________________________________________________
- Check the MEAs
  - ____________________________________________________________
- Check the references
  - ____________________________________________________________
- Check the TTL configuration.
  - ____________________________________________________________
- Test synchronization.
  - ____________________________________________________________
- Test 3D reconstruction.
  - ____________________________________________________________
- Check stimulator and pacing functions.
  - ____________________________________________________________
- Check the ablation system.
  - ____________________________________________________________
- Check the needles for ablation and backup.
  - ____________________________________________________________
- Check Tank connection and water bath recirculation.
  - ____________________________________________________________
- Check if OBS, camera, real-time clock and surgical camera work.
  - ____________________________________________________________
- Create experiment folders in the SSD Drive
  - folder: yearmounthday-experiment:
    - Electric -> 6x (filter and no_filter)
    - Optic
    - media -> screenshots + photos_videos + OBSrecording + 3D
  - ____________________________________________________________
- Check the Balloon and backup.
  - ____________________________________________________________
- Check the Anesthesia table.
  - ____________________________________________________________
- Check and organize surgical components.
  - ____________________________________________________________
- Check solution needs for preparation.
  - ____________________________________________________________
- Confirm that appropriate biological, sharps, and chemical waste-disposal arrangements are available according to institutional procedures.
  - ____________________________________________________________
- Print documents for the experiment.
  - ____________________________________________________________

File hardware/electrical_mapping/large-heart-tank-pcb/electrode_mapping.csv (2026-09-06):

electrode_label | kicad_reference | connector | connector_pin | grid_row_by_kicad_y | grid_column_by_kicad_x | kicad_x_mm | kicad_y_mm
E01 | U1 | J1 | 1 | 3 | 5 | 300.000 | 188.000
E02 | U2 | J1 | 2 | 2 | 4 | 256.750 | 143.425
E03 | U3 | J1 | 3 | 3 | 4 | 256.750 | 188.000
E04 | U4 | J1 | 4 | 3 | 3 | 213.500 | 188.000
E05 | U5 | J1 | 5 | 2 | 2 | 170.250 | 143.425
E06 | U6 | J1 | 6 | 3 | 2 | 170.250 | 188.000
E07 | U7 | J1 | 7 | 3 | 1 | 127.000 | 188.000
E08 | U8 | J1 | 8 | 2 | 1 | 127.000 | 143.425
E09 | U9 | J1 | 9 | 1 | 1 | 127.000 | 96.950
E10 | U10 | J1 | 10 | 1 | 2 | 170.250 | 96.950
E11 | U11 | J1 | 11 | 1 | 3 | 213.500 | 96.950
E12 | U12 | J1 | 12 | 2 | 3 | 213.500 | 143.425
E13 | U13 | J1 | 13 | 1 | 4 | 256.750 | 96.950
E14 | U14 | J1 | 14 | 1 | 5 | 300.000 | 96.950
E15 | U15 | J1 | 15 | 2 | 5 | 300.000 | 143.425
SPARE/NC |  | J1 | 16

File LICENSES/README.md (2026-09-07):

# License texts

- `MIT.txt` — MIT License (`MIT`)
- `CERN-OHL-P-2.0.txt` — CERN Open Hardware Licence Version 2 – Permissive (`CERN-OHL-P-2.0`)

General documentation and experimental protocols are licensed under CC BY 4.0:

https://creativecommons.org/licenses/by/4.0/

See [`../LICENSE.md`](../LICENSE.md) for the complete mapping.

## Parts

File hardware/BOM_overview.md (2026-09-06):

# Hardware Bill of Materials — Overview

This document provides a high-level overview of the hardware used across the multimodal mapping platform.

It is not intended to replace the subsystem-specific BOMs. Quantities vary according to experimental configuration.

## Perfusion and fluidics

| Item | Representative implementation | Notes |
|---|---|---|
| Peristaltic pump | Laboratory pump | STEP/DIR-compatible implementation |
| Main/bulk perfusate reservoir | Laboratory/custom reservoir | Capacity depends on preparation |
| Perfusion/head reservoir | Laboratory/custom reservoir | Used where hydrostatic pressure control is required |
| Serpentine heat exchanger | Custom/laboratory fabricated | CAD support is provided separately |
| Bubble trap | Inline | Inline bubble-management component |
| Analog flow meter | Inline | Used for visual flow verification |
| Digital flow/temperature sensor | Sensirion SLF3S-4000B | Current sensor firmware identifies this device |
| Digital pressure sensor | Honeywell digital pressure sensor | Honeywell digital pressure-sensor implementation |
| Tubing | Laboratory perfusion tubing | Medical/laboratory perfusion tubing; dimensions depend on interface |
| Valves / stopcocks / Luer fittings | Commercial | Configuration dependent |
| Small-heart aortic cannula | Custom | CAD/drawings provided in `cad/` |
| Large-heart coronary cannulation interfaces | Custom/commercial combination | Preparation-specific interface |
| Epi-endo coronary cannulation interface | Custom/commercial combination | Preparation-specific interface |

## Physiological monitoring electronics

| Item | Representative implementation | Notes |
|---|---|---|
| Sensor-node MCU | Arduino Nano | One node per instrumented perfusion line in the current implementation |
| Wireless module | nRF24L01 | One per sensor node |
| Flow/temperature sensor | Sensirion SLF3S-4000B | I²C |
| Pressure sensor | Honeywell digital sensor | Model-specific implementation |
| Tank temperature probe | K-type thermocouple implementation | K-type thermocouple interface |
| Gateway MCU | ESP32-S3 development board | One gateway |
| Gateway radio | nRF24L01 | Receives sensor-node packets |
| USB connection | ESP32-S3 to experiment computer | Serial data path |

## Optical mapping

| Item | Representative implementation | Notes |
|---|---|---|
| Optical mapping cameras | High-speed cameras | High-speed optical-mapping implementation |
| Camera count | 3 small-heart; 2 large-heart/epi-endo representative implementations | Experiment dependent |
| Lens | 25 mm | 25 mm optical-mapping implementation |
| Excitation LEDs | ~650 nm | Six LEDs used in the representative small-heart arrangement |
| Emission filter | ~715 nm long-pass | Long-pass optical filter |
| Mirror | ~45° epi-endo optical view | Holder CAD provided under `cad/epi-endo/` |
| Camera/LED mounts | Commercial/custom | Commercial/custom mounting |

## Electrical mapping

| Item | Representative implementation | Notes |
|---|---|---|
| Electrical acquisition | Intan RHD / Open Ephys implementation | Configuration-dependent channel count |
| Small-heart MEAs | Three 16-electrode arrays | RA, LA, ventricular placement |
| Small-heart torso-tank electrodes | 60 electrodes | 10 electrodes per face in the representative hexagonal tank |
| Large-heart tank PCB | 15 electrodes per PCB | Six PCBs used around the representative tank |
| Epi-endo MEAs | Paired epicardial/endocardial arrays | Preparation-specific geometry |
| Reference/ground interfaces | Configuration dependent | Reference arrangement depends on mapping modality |

## Electrical stimulation

| Item | Representative implementation | Notes |
|---|---|---|
| Constant-current stimulator | Single-channel PNP current-mirror implementation | Paper-associated validated implementation |
| Compliance supply | Four 9 V batteries in series | Approximately 42 V practical compliance reported for the implementation |
| Output range | ~100 µA to 45 mA | Validated current-mirror implementation |
| Trigger isolation | Isolated trigger interface | Isolated trigger interface |
| Stimulation catheter/electrodes | Bipolar | Experiment dependent |

## Synchronization

| Item | Representative implementation | Notes |
|---|---|---|
| Timing controller | Teensy 4.1 | Current synchronization firmware |
| Timing output | TTL-level timing signal | 500 Hz representative synchronization signal |
| Optical camera trigger interface | Digital timing connection | Camera-specific trigger interface |
| Electrical acquisition timing input | Open Ephys digital input | Representative implementation |

## 3D reconstruction acquisition

| Item | Representative implementation | Notes |
|---|---|---|
| Stepper motor | NEMA 14 | Used for controlled preparation rotation |
| Stepper driver | STEP/DIR-compatible driver | STEP/DIR-compatible implementation |
| Motor controller | Arduino-compatible controller | Firmware provided under `firmware/stepper_motor_control/` |
| Microstepping | 16× representative configuration | Must match driver jumpers/settings |
| Rotational mechanical assembly | Configuration-specific | CAD provided under `cad/` |
| Reconstruction camera option 1 | EVT camera | LabVIEW acquisition software |
| Reconstruction camera option 2 | Imaging Source USB camera | Python/OpenCV acquisition software |
| Calibration object | ChArUco-based calibration object | Calibration performed using MC-Calib |

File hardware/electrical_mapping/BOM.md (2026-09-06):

# Electrical Mapping BOM

## Acquisition

| Component | Representative implementation | Notes |
|---|---|---|
| Electrical acquisition platform | Intan RHD / Open Ephys |  |
| Acquisition computer | Laboratory workstation | Configuration dependent |
| Digital synchronization input | Open Ephys digital input | Receives common timing signal |
| Headstage | Variable Quantity | Intan RHD 64-Channel Headstage |
| Digital Cable | Variable Quantity | RHD SPI Interface Cables |
| Electrode adapter cabling | Custom/commercial |  2x Intan 36-pin Wire Adapter per headstage|

## Contact MEAs

| Component | Quantity | Representative implementation |
|---|---:|---|
| Small-heart right-atrial MEA | 1 | 16 electrodes |
| Small-heart left-atrial MEA | 1 | 16 electrodes |
| Small-heart ventricular MEA | 1 | 16 electrodes |
| Epi-endo epicardial MEA | 1 | Configuration-specific |
| Epi-endo endocardial MEA | 1 | Configuration-specific |
| Headstage | 1 | Intan RHD 64-Channel Headstage (adapt to your needs)|
| Wiring harness | 1 | Intan 36-pin Wire Adapter |

## Small-heart torso tank

| Component | Quantity | Representative implementation |
|---|---:|---|
| Hexagonal tank | 1 | Acrylic tank custom manufacture |
| Tank electrodes | 60 | 10 per face × 6 faces |
| Electrode material | 60 | Historical stainless-steel and later Ag/AgCl implementations |
| Reference network | 1 | Wilson central terminal implementation |
| Headstage | 1 | Intan RHD 64-Channel Headstage |
| Wiring harness | 1 set | 2x Intan 36-pin Wire Adapters |

## Large-heart tank

| Component | Quantity | Representative implementation |
|---|---:|---|
| Large-heart tank electrode PCB | 6 | 15 electrodes per PCB |
| PCB support assembly | 1 | Custom CAD under `cad/large-heart/transparent-pcb-support/` |
| PCB connector/cabling | 6 sets | Current design uses a 1×16, 2.54 mm header footprint |
| Headstage | 2 | Intan RHD 64-Channel Headstage |
| Wiring harness | 2 sets | 2x Intan 36-pin Wire Adapters per Headstage|

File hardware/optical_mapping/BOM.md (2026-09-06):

# Optical Mapping BOM

Quantities are configuration dependent.

| Component | Quantity | Specification | Notes |
|---|---:|---|---|
| High-speed optical camera | 2–3 | High-speed optical-mapping camera | Camera count depends on configuration |
| Lens | 1 per camera | Approximately 25 mm | Used in the  optical-mapping implementation |
| Long-pass emission filter | 1 per camera | Approximately 715 nm | Positioned in the fluorescence collection path |
| Excitation LED | Up to 6 in the small-heart implementation | Approximately 650 nm | Quantity and placement depend on optical access |
| LED driver / power supply | As required | Compatible with excitation LEDs | Laboratory illumination supply |
| Camera mount | 1 per camera | Rigid adjustable support | Commercial/custom |
| LED mount | As required | Adjustable | Commercial/custom |
| Optical mirror | 1 for epi-endo | Mounted at approximately 45° | Provides additional optical access |
| Mirror holder | 1 | Custom | CAD under `cad/epi-endo/` |
| Trigger cable/interface | 1 per synchronized camera | Camera timing input | Electrical interface is camera specific |

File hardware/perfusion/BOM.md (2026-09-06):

# Perfusion Hardware BOM

Quantities depend on preparation and experimental configuration.

| Component | Quantity | Specification | Status / notes |
|---|---:|---|---|
| Peristaltic pump | 1 | Laboratory perfusion pump | Any model that can deliver more than 150mL/min |
| Main/bulk reservoir | 1+ | Large Beaker | 2L for small hearts/4L for large hearts |
| Head/perfusion reservoir | 1 | [`Water-Oil separator`](https://stonylab.com/products/b09mmwj8zc-water-oil-receiver-separator) works well for this application | Prioritize larger volumes at least 200mL |
| Analog flow meter | 1 per active line | Appropriate perfusion flow range | Selected according to the expected flow range of the preparation |
| Serpentine heat exchanger | 1 per active line | Laboratory helical condenser | Related CAD support available |
| Inline Bubble trap | 1 per active line | [`PEEK 300uL bubble trap`](https://www.precigenome.com/microfluidic-fluidic/bubble-trap) |  |
| Digital flow/temperature sensor | 1 per instrumented line | [`Sensirion SLF3S-4000B`](https://sensirion.com/products/catalog/SLF3S-4000B) | Current firmware implementation |
| Digital pressure sensor | 1 per instrumented line | Honeywell digital pressure sensor | Relative liquid-pressure measurement appropriate to the perfusion range |
| Tubing 6mm OD | As required (at least 2 meters) | Medical grade | Silicone or PVC, ID/OD 4/6mm. NOTE: Some manufactures have internal grooves in their tubing, those will leak if used. |
| Tubing 8mm OD | As required (at least 1 meter) | Medical grade | Silicone or PVC, ID/OD 6/8mm. Used to connect the flow sensor and the main reservoir. NOTE: Some manufactures have internal grooves in their tubing, those will leak if used. |
| 2-way Luer connectors | As required | Commercial |  |
| 6mm to 6mm quick connect | As required | Commercial | Useful for quickly changing configurations |
| 8mm to 6mm quick connectors | As required | Commercial | Useful for connecting the flow sensor (8mm) to the other tubing. |
| Three-way stopcocks | As required | Medical grade | Facilitate the removal of air bubbles in different points of the perfusion line. Small-heart cannula includes a modified stopcock interface |
| Aortic cannula | 1 | Custom | Made from a modified 3-way stopcock |
| Coronary cannula / interface | 1–2 | Preparation specific | Large-heart / epi-endo. Made from a blunt 14G needle and a silicone stopper with varying sizes depending on the coronary size gauge. |
| Clamps and tubing holders | As required | Commercial/custom | See CAD for custom supports |
| Carbogen gas interface | 1+ | 95% O₂ / 5% CO₂ experimental supply |  |

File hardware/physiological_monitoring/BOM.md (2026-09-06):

# Physiological Monitoring BOM

## Per instrumented perfusion line

| Component | Quantity | Implementation | Notes |
|---|---:|---|---|
| Arduino Nano | 1 | Sensor-node controller | Other MCUs can be adapted |
| nRF24L01 | 1 | Wireless sensor-node link | nRF24L01 radio link |
| Sensirion SLF3S-4000B | 1 | Flow + inline temperature | Current firmware |
| Honeywell pressure sensor | 1 | Digital I²C pressure measurement | Honeywell digital pressure-sensor implementation |
| Battery power (5V) | 1 | Appropriate regulated battery |  |
| Wiring / connectors | As required | I²C + radio + power |  |

## Gateway

| Component | Quantity | Implementation | Notes |
|---|---:|---|---|
| ESP32-S3 development board | 1 | Gateway MCU | Current implementation |
| nRF24L01 | 1 | Receives node packets | Gateway radio link |
| USB cable | 1 | Gateway to experiment computer | Data + power as configured |

## Additional temperature monitoring

| Component | Quantity | Implementation | Notes |
|---|---:|---|---|
| K-type thermocouple | 1+ | Tank/chamber temperature |  |
| Thermocouple interface | 1 | SPI | Module MAX31855 |

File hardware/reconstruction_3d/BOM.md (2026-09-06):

# 3D Reconstruction Acquisition BOM

| Component | Quantity | Implementation | Notes |
|---|---:|---|---|
| Stepper motor | 1 | NEMA 14 | Current rotational implementation |
| Stepper driver | 1 | DRV8825 | STEP/DIR driver used in the implementation |
| Motor controller | 1 | Arduino-compatible | See firmware |
| Timing belt | 1 | Configuration specific | Small/large assemblies use different lengths |
| Pulleys | 2+ | Configuration specific | See CAD assembly |
| Rotation shaft | 1 | Configuration specific | See CAD |
| Bearings | 2+ | Configuration specific | See CAD |
| Reconstruction camera | 1 | EVT or Imaging Source USB implementation | Capture software differs |
| Camera lens | 1 | Camera dependent | Selected according to the reconstruction camera and field of view |
| Calibration object | 1 | ChArUco-based | MC-Calib workflow |

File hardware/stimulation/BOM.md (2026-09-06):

# Stimulation Hardware — Architecture-Level BOM

This file summarizes the hardware architecture of the validated single-channel constant-current stimulator used with the platform.

| Component | Implementation | Notes |
|---|---|---|
| Current-source topology | PNP current mirror | Single-channel constant-current architecture |
| High-voltage supply | 4 × 9 V batteries in series | Isolated battery supply |
| Trigger interface | Isolated trigger | Receives stimulation commands from the control system |
| Output interface | Bipolar stimulation connection | Connected to the experiment-specific stimulation electrodes/catheter |
| Current-setting network | Adjustable current-control network | Provides the experimental output-current setting |
| PNP transistor stage | Matched/current-mirror stage | Constant-current output stage |
| Protection/interface components | As implemented in the validated circuit | Supports controlled experimental operation |
| Enclosure | Laboratory/custom | Electrically isolated experimental housing |
| Stimulation catheter/electrodes | Bipolar | Experiment dependent |

Operating characteristics are described in [`README.md`](README.md).

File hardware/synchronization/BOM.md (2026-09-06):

# Synchronization BOM

| Component | Quantity | Implementation | Notes |
|---|---:|---|---|
| Timing controller | 1 | Teensy 4.1 | Current firmware target |
| USB cable | 1 | Computer/controller connection | Document if separate power is used |
| Camera trigger cables | 1 per triggered camera | Configuration dependent | Dependent on camera configuration |
| Intan RHD System/Open Ephys digital-input cable | 1 | Timing reference | BNC terminated cable |
| Signal generator | 1 | Any signal generator to generate the TTL signal reliably | Can be interchanged with the teensy output. |

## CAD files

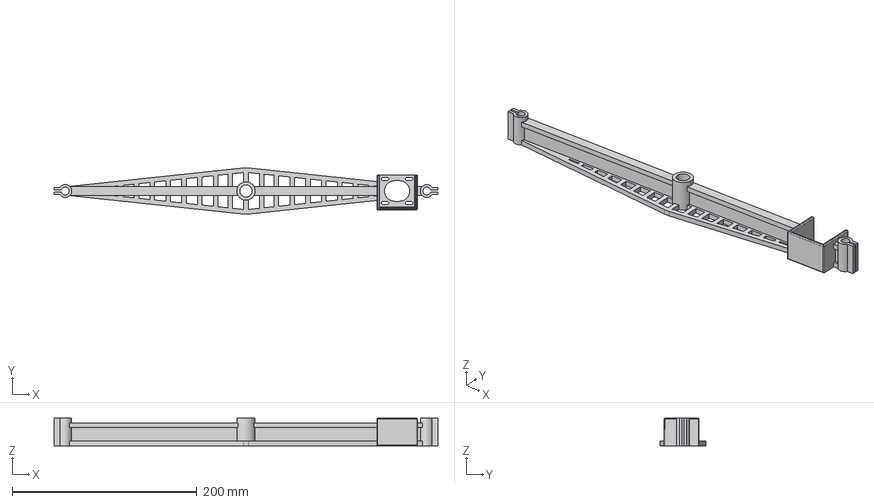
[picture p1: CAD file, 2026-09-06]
cad/large-heart/main-support/MainSupport.step
415.5 x 50.0 x 30.0 mm

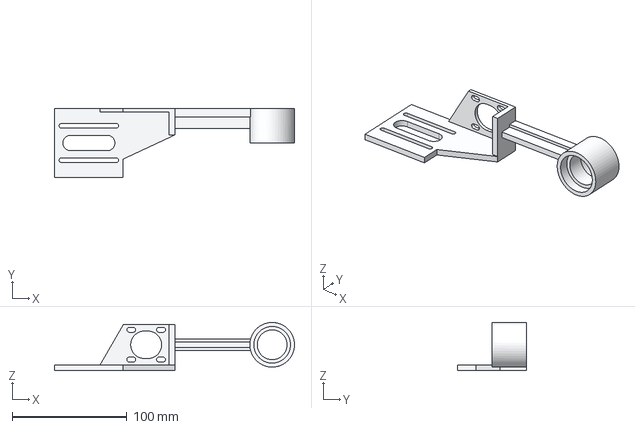
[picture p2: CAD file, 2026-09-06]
cad/small_heart/main_support/MainSupport.stp
209.5 x 60.0 x 42.0 mm

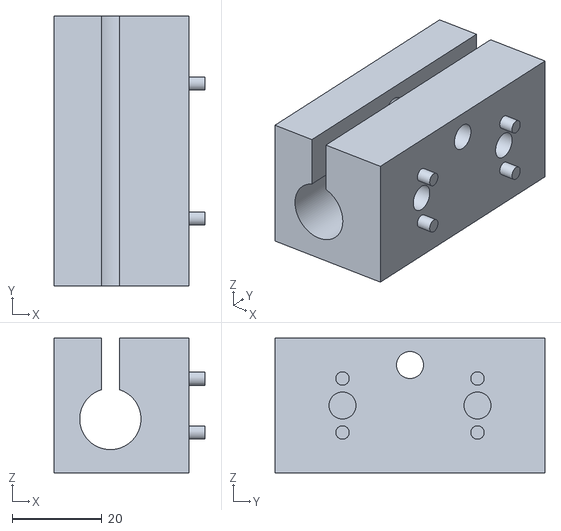
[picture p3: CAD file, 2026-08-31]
cad/small_heart/main_support/MainSupportHolder.stl
33.5 x 60.0 x 30.0

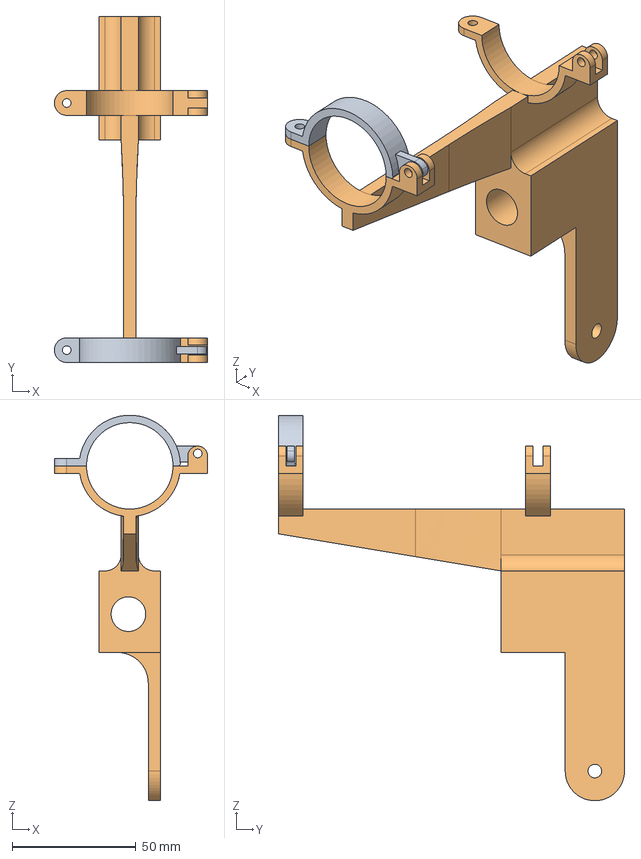
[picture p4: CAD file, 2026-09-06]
cad/small_heart/serpentine_support/AssemblySerpentineSupport.step
62.0 x 140.0 x 156.0 mm

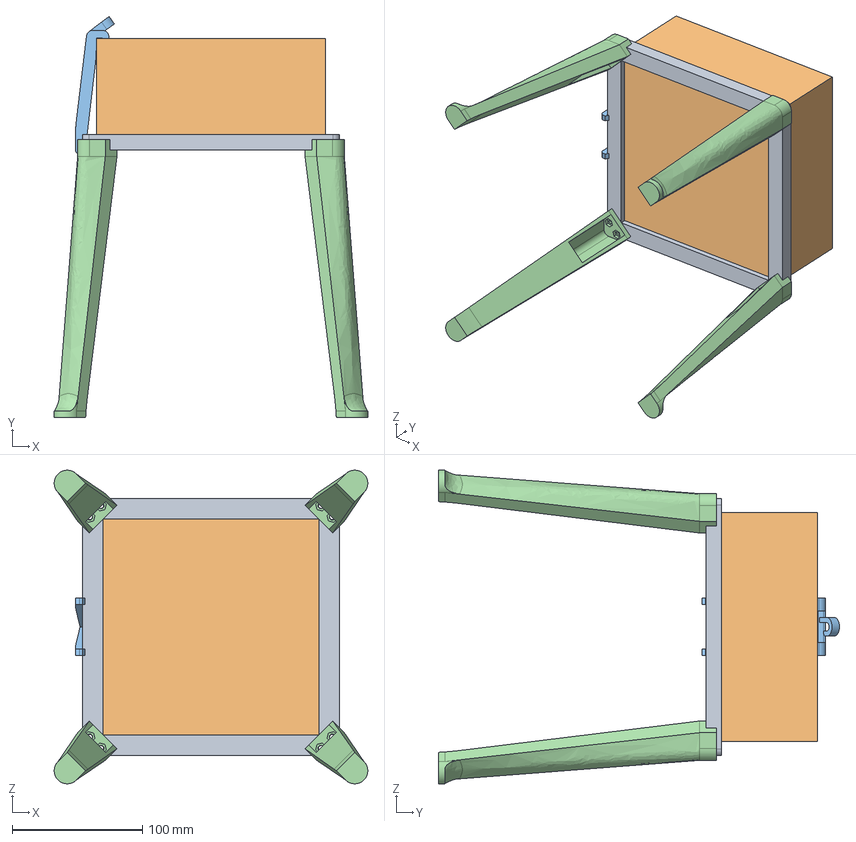
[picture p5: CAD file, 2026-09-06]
cad/epi-endo/main-support/Epi-EndoAssembly.step
240.4 x 307.4 x 240.4 mm
Base_1
Tank
TubingClamp
LegV3 x 4

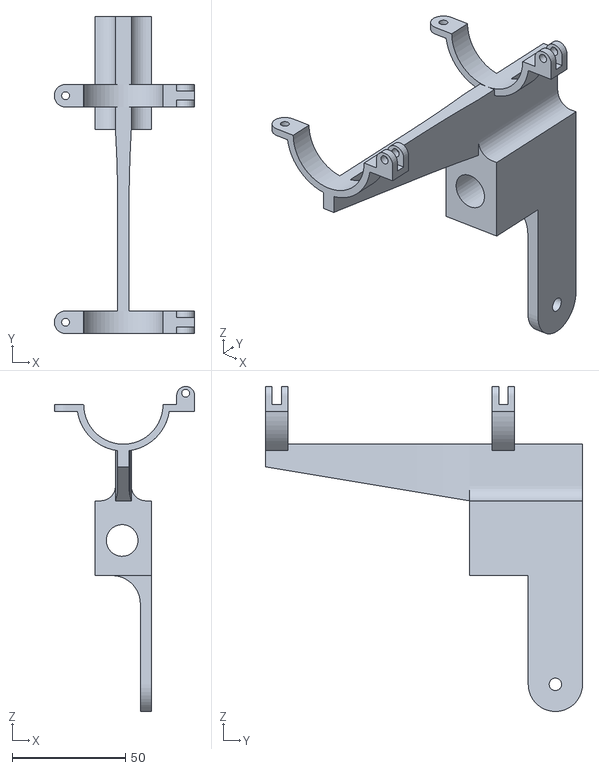
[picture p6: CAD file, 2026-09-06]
cad/small_heart/serpentine_support/MainSerpentineSupport.stl
62.0 x 140.0 x 143.5

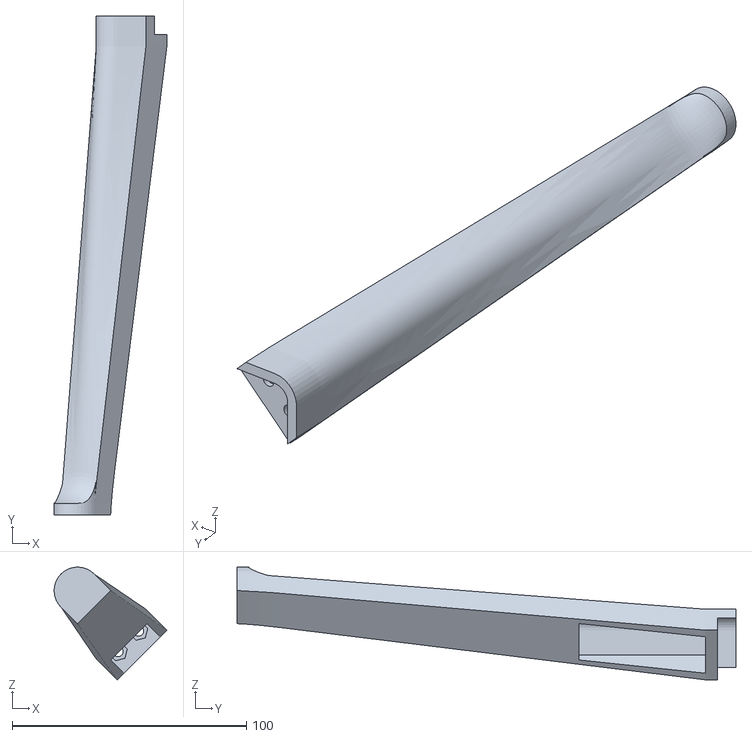
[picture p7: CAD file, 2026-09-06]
cad/epi-endo/main-support/Leg.stl
48.1 x 213.0 x 48.1

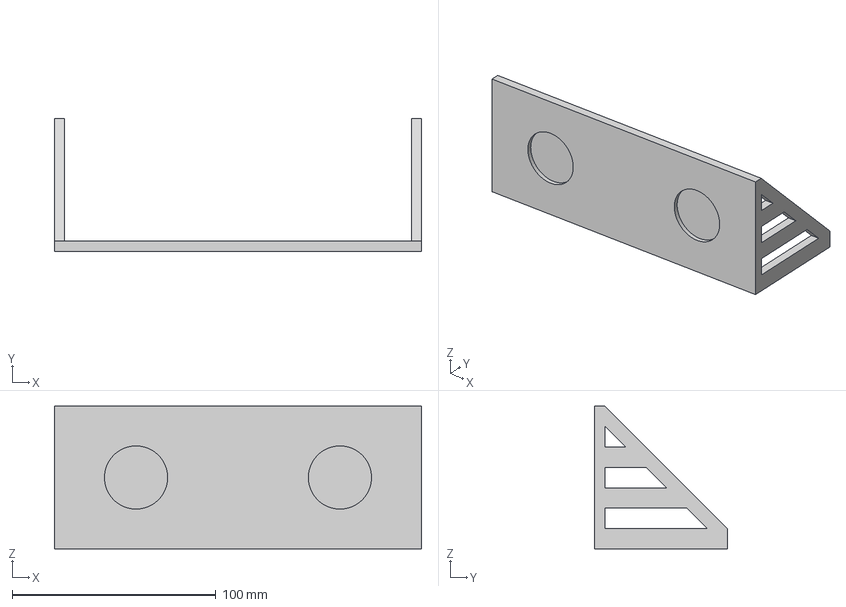
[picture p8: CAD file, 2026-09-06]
cad/epi-endo/mirror-support/MirrorSupport.step
180.0 x 65.1 x 70.0 mm

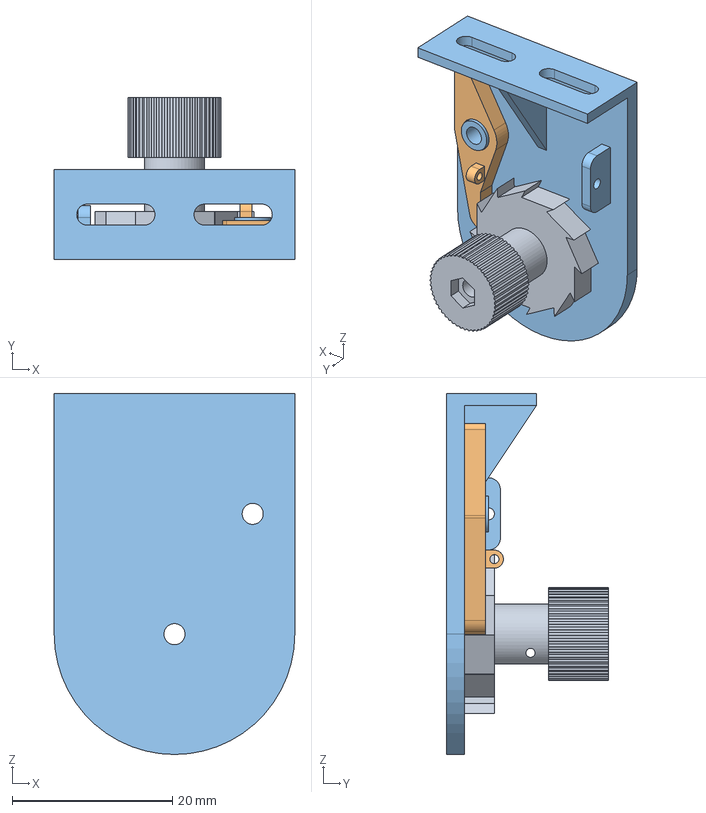
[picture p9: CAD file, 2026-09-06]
cad/large-heart/heart-support/RatchetHousing.step
30.0 x 20.2 x 45.0 mm
BoltHead
Pawl

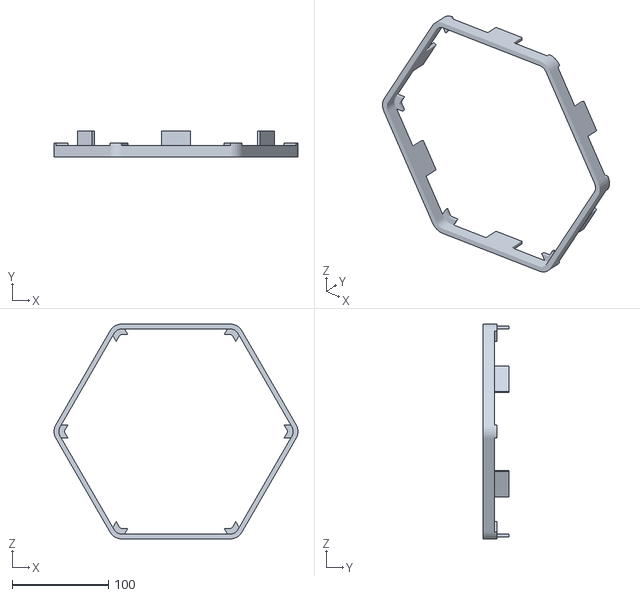
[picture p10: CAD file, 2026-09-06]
cad/large-heart/transparent-pcb-support/TopExternalSupport.stl
253.2 x 26.5 x 223.0

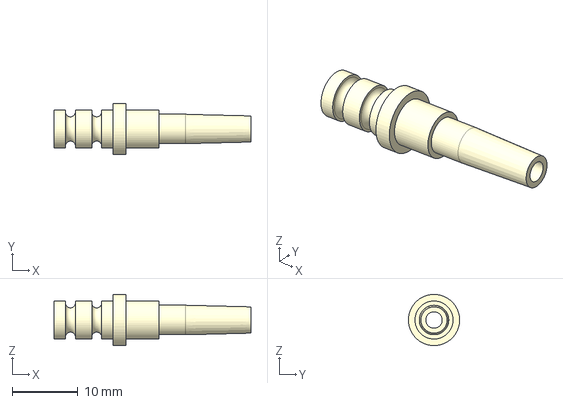
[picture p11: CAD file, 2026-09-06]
cad/small_heart/cannula/Connection.stp
30.0 x 7.79 x 7.80 mm

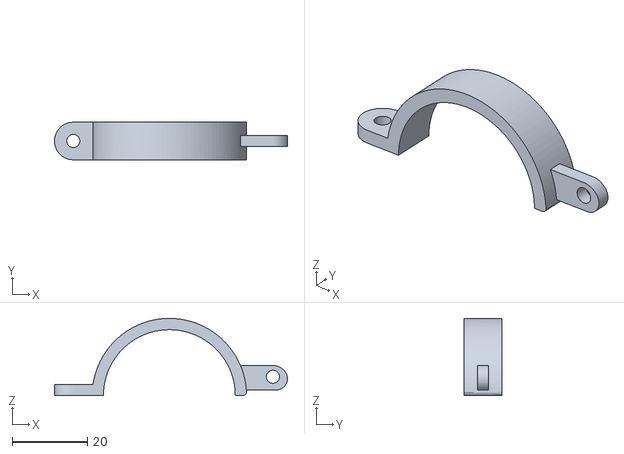
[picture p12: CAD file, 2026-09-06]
cad/small_heart/serpentine_support/SerpentineHolder.stl
61.9 x 10.0 x 20.5

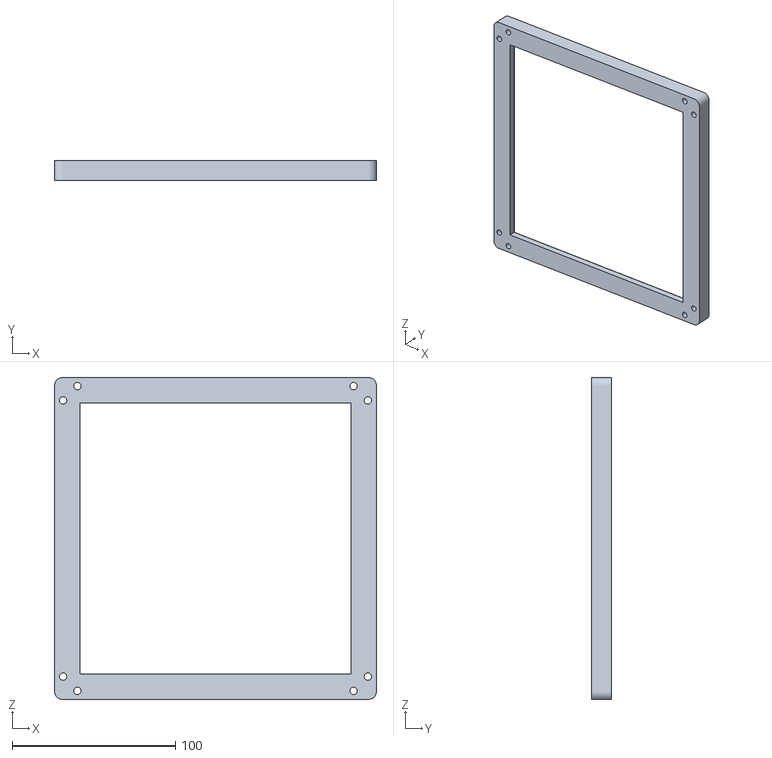
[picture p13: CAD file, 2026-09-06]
cad/epi-endo/main-support/Base.stl
197.0 x 12.0 x 197.0

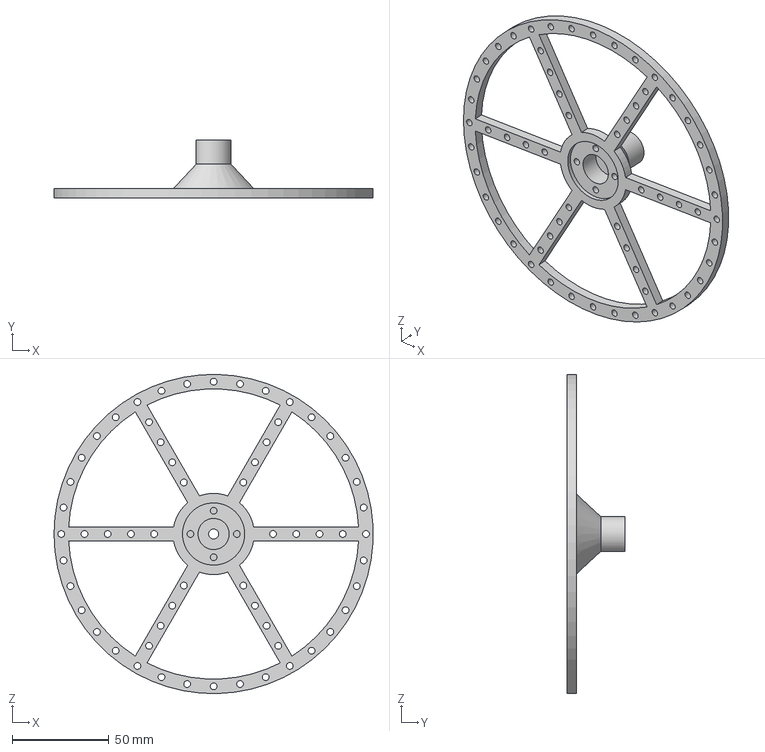
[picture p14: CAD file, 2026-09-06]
cad/large-heart/heart-support/Circular_Support.step
164.9 x 30.0 x 164.9 mm

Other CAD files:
cad/large-heart/transparent-pcb-support/Connection.stl
cad/small_heart/cannula/Spacer.step
cad/large-heart/heart-support/Housing.stl
cad/large-heart/transparent-pcb-support/TopInternalSupport.stl
cad/epi-endo/main-support/Epi-EndoAssembly.f3z
cad/epi-endo/main-support/TubingHolder.stl
cad/epi-endo/mirror-support/MirrorSupport.f3d
cad/epi-endo/mirror-support/MirrorSupport.stl
cad/large-heart/heart-support/Circular_Support.f3z
cad/large-heart/heart-support/Pawl.stl
cad/large-heart/heart-support/Ratchet.stl
cad/large-heart/heart-support/RatchetHousing.f3d
cad/large-heart/main-support/MainSupport.f3d
cad/large-heart/main-support/MainSupport.stl
cad/large-heart/transparent-pcb-support/BottomInternalSupport.stl
cad/large-heart/transparent-pcb-support/Transparent_PCB_Support.f3d
cad/small_heart/cannula/Connection.ipt
cad/small_heart/cannula/Separator.ipt
cad/small_heart/cannula/Separator.stl
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

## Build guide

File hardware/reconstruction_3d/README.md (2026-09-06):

# 3D Reconstruction Acquisition Hardware

This directory documents the hardware used to acquire rotational image sequences for experiment-specific 3D reconstruction.

The acquisition hardware is separate from the software that performs image capture and later reconstruction processing.

## Mechanical principle

The cardiac preparation is rotated through a complete revolution while images are captured at known angular increments.

The acquisition uses:

- 100 unique angular views;
- 360° total rotation;
- 3.6° between consecutive views.

## Rotational hardware

The current system uses:

- NEMA 14 stepper motor;
- STEP/DIR-compatible stepper driver;
- Arduino-compatible motor controller;
- 16× microstepping in the firmware configuration;
- configuration-specific pulleys, belts, shafts, bearings, and supports.

The exact mechanical arrangement differs between small-heart and large-heart assemblies.

CAD:

[`../../cad/`](../../cad/)

Firmware:

[`../../firmware/stepper_motor_control/`](../../firmware/stepper_motor_control/)

## Image-acquisition options

### EVT / LabVIEW

The EVT-camera implementation is documented under:

[`../../software/3D_reconstruction_capture_labview/`](../../software/3D_reconstruction_capture_labview/)

### Imaging Source USB / Python

The Imaging Source USB-camera implementation is documented under:

[`../../software/3D_reconstruction_capture_python/`](../../software/3D_reconstruction_capture_python/)

## Calibration

Camera calibration is performed using MC-Calib.

The HEartLab repository should link to the upstream MC-Calib instructions rather than duplicating their calibration procedure.

A ChArUco-based calibration object was used in the HEartLab reconstruction workflow.

## Reconstruction processing

The subsequent silhouette/space-carving/mesh processing software is documented separately under the software directory.

## Verification

Before rotational acquisition:

- verify motor direction;
- verify microstepping;
- verify pulley/transmission ratio;
- verify 3.6° movement if using 100 views;
- verify full 360° return;
- verify that tubing/cables do not obstruct rotation;
- verify camera focus and exposure;
- verify calibration-object visibility when required;
- verify image count and naming;
- verify mechanical stability between captures.

See [`BOM.md`](BOM.md).

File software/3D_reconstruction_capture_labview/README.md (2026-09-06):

# 3D Reconstruction Image Acquisition — LabVIEW / EVT Cameras

This directory contains the LabVIEW software used by HEartLab to automate rotational image acquisition for experiment-specific three-dimensional reconstruction of cardiac preparations.

The software coordinates image capture from the **EVT camera system used in the HEartLab implementation** with controlled rotation of the preparation.

> [!IMPORTANT]
> This LabVIEW application is configured for the EVT camera system used in HEartLab. Because the camera interface and acquisition workflow are manufacturer- and configuration-specific, the application should **not be expected to work directly with generic USB cameras or cameras from other manufacturers** without modification.

A separate Python/OpenCV implementation used with the Imaging Source USB-camera setup is available at [`../3D_reconstruction_capture_python/`](../3D_reconstruction_capture_python/).

## Purpose

The application performs the **image-acquisition stage** of the reconstruction workflow. An acquisition consists of approximately 100 images acquired over one complete 360° rotation of the preparation.

The resulting multi-view image sequence is subsequently used for segmentation and 3D surface reconstruction. This LabVIEW application does **not** itself perform the complete surface-reconstruction process.

## Acquisition principle

```text
Initial orientation
        |
        v
Capture image
        |
        v
Rotate preparation
        |
        v
Wait for mechanical stabilization
        |
        v
Capture next image
        |
        v
Repeat until 360° is covered
```

For a 100-view acquisition:

```text
360° / 100 = 3.6° per image
```

## Hardware interface

The software communicates with the rotational-stage Arduino controller through a serial connection.

The corresponding firmware is available at:

[`../../firmware/stepper_motor_control/`](../../firmware/stepper_motor_control/)

The general architecture is:

```text
EVT camera
    |
    v
LabVIEW acquisition software
    |
    +-- image capture
    |
    +-- serial rotation command
              |
              v
           Arduino
              |
          STEP / DIR
              v
       Stepper driver
              |
              v
       Stepper motor
              |
              v
      Rotating preparation
```

## Representative acquisition parameters

| Parameter | Value |
|---|---:|
| Total rotation | 360° |
| Number of views | 100 |
| Angular increment | 3.6° |

These values correspond to an implementation and may be adapted when a different angular sampling density is required.

## Camera compatibility

The current LabVIEW application was developed around EVT cameras and their associated acquisition interface.

Compatibility with the following should **not** be assumed:

- generic USB webcams;
- USB machine-vision cameras using unrelated drivers;
- cameras from different manufacturers;
- different EVT camera models using incompatible drivers or APIs;
- operating-system or driver versions not tested with the original setup.

Porting the application to another camera may require changes to camera discovery, driver calls, acquisition configuration, exposure control, frame capture, image saving, trigger behavior, and error handling.

## Tested environment

The HEartLab implementation was used with:

- LabVIEW 2019;
- 64-bit architecture;
- Windows 10/11;
- EVT HR-1800-S-M camera.

## Operation

A typical acquisition sequence is:

1. position the preparation at the initial orientation;
2. verify the EVT camera connection;
3. verify camera focus, exposure, and field of view;
4. verify any calibration object required by the reconstruction workflow;
5. connect the Arduino rotational controller;
6. select or verify the serial port;
7. select the output directory;
8. verify the angular increment and intended number of views;
9. begin automated acquisition;
10. allow the application to alternate image capture and rotation;
11. verify that all expected images were saved;
12. preserve the acquisition parameters with the dataset.

## Output

The output generated by the current LabVIEW application:

- 101 images (the first and last images should be the same for validation);
- ".tiff" format;
- 1600x1000 pixels;
- 8-bit depth;

## Calibration and reconstruction

The image-acquisition stage is followed by camera calibration and the silhouette/space-carving workflow provided in [`../3d_reconstruction_processing/`](../3d_reconstruction_processing/). Camera calibration follows the upstream MC-Calib procedure.

## Verification

Before acquiring reconstruction images:

- verify serial communication;
- verify the mechanical transmission ratio;
- confirm that the preparation can rotate without tubing or cable interference;
- verify EVT camera focus and exposure;
- verify that images are written to the intended directory;
- confirm that the final acquisition contains the expected number of views.

> [!CAUTION]
> The software and acquisition parameters are provided as a representative HEartLab implementation. Camera communication, angular calibration, file output, and mechanical rotation must be independently verified before experimental use.

See the repository-level `DISCLAIMER.md`.

## Third-party RHYTHM component

The file `saveNumberedImage.vi` was obtained from the **RHYTHM open-source imaging toolkit** and is redistributed in accordance with the RHYTHM software license.

RHYTHM is distributed under the **MIT License**. The original copyright notice is:

> Copyright (c) 2018 optocardiography

The applicable license notice is preserved in:

[`RHYTHM_LICENSE.txt`](RHYTHM_LICENSE.txt)

RHYTHM is described in:

**Gloschat C. et al. _RHYTHM: An Open Source Imaging Toolkit for Cardiac Panoramic Optical Mapping_. Scientific Reports. 2018;8:2921.**

Source project:

`https://github.com/optocardiography/Rhythm-1.2`

See [`THIRD_PARTY.md`](THIRD_PARTY.md) for third-party attribution information.

## Third-party software

LabVIEW, National Instruments components, EVT camera drivers, and other third-party software are not redistributed by HEartLab.

Users must obtain required third-party software and drivers from their respective developers or manufacturers.

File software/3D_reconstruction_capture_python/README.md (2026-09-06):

# 3D Reconstruction Image Acquisition — Python / Imaging Source USB Camera

This directory contains the Python application used by HEartLab to automate rotational image acquisition for experiment-specific three-dimensional reconstruction of cardiac preparations.

The application was developed for the **USB camera from The Imaging Source used in the HEartLab implementation**, accessed through OpenCV, and coordinates image capture with the Arduino-controlled rotational stage.

> [!IMPORTANT]
> The current implementation was developed around the HEartLab Imaging Source USB-camera setup. Other cameras that are accessible through OpenCV may also work, but compatibility, camera controls, image format, exposure behavior, and driver support must be independently verified.

The repository also contains a separate LabVIEW acquisition implementation for the EVT camera system.

## Purpose

The application performs the **image-acquisition stage** of the 3D reconstruction workflow.

A representative acquisition captures 100 unique views over one complete 360° rotation:

```text
Image 000:   0.0°
Image 001:   3.6°
Image 002:   7.2°
...
Image 099: 356.4°
```

After the final image, the corrected implementation can perform one additional 3.6° movement to return the rotational stage to its initial 360°/0° orientation without saving a duplicate image.

The acquired images are subsequently used for segmentation and 3D surface reconstruction. This application does **not** itself perform segmentation, space carving, mesh generation, or other reconstruction processing.

## System architecture

```text
Imaging Source USB camera
          │
          ▼
 Python acquisition software
          │
          ├── TIFF image capture
          │
          └── serial angle command
                    │
                    ▼
                 Arduino
                    │
                STEP / DIR
                    ▼
             Stepper driver
                    │
                    ▼
             Stepper motor
                    │
                    ▼
            Rotating support
```

The corresponding rotational-stage firmware is located in:

[`../../firmware/stepper_motor_control/`](../../firmware/stepper_motor_control/)

## Representative acquisition parameters

| Parameter | Representative value |
|---|---:|
| Total angular coverage | 360° |
| Number of unique images | 100 |
| Angular increment | 3.6° |
| Output format | TIFF |
| Stepper-controller baud rate | 57600 baud |
| Default settling delay | 3 s |

The number of images and settling delay can be adjusted in the graphical interface.

If the number of images is changed, the angular increment is calculated as:

```text
angular increment = 360° / number of images
```

The motor and mechanical transmission must be capable of reproducing the requested increment with sufficient accuracy.

## Camera compatibility

The current implementation opens the camera through OpenCV.

On Windows, the corrected version first attempts to use the DirectShow backend and falls back to OpenCV's default backend if necessary.

The application was developed for the HEartLab **Imaging Source USB camera**. Compatibility with other cameras should not be assumed.

Potential camera-dependent differences include:

- device enumeration;
- supported resolutions;
- pixel format;
- exposure range;
- automatic versus manual exposure;
- gain range;
- driver behavior;
- buffering;
- bit depth;
- TIFF output;
- OpenCV backend support.

The exposure and gain sliders in the application use OpenCV's generic camera-property interface. The numeric values are therefore **camera- and backend-dependent** and must be verified for the connected camera.

## Relationship to the LabVIEW / EVT implementation

Two rotational image-acquisition implementations are provided:

The two programs perform the same general task but use different camera interfaces.

Both can use the HEartLab Arduino rotational-stage firmware when configured with a compatible serial protocol.

## Requirements

The Python program requires:

- Python 3;
- OpenCV (`opencv-python`);
- PySerial (`pyserial`);
- Tkinter;
- a compatible camera driver;
- the HEartLab Arduino rotational-stage controller.

Python package requirements are listed in:

[`requirements.txt`](requirements.txt)

Install the Python dependencies with:

```bash
python -m pip install -r requirements.txt
```

Tkinter is included with standard Python distributions on Windows. On some Linux distributions it may need to be installed separately through the operating system package manager.

## Running the application

Run:

```bash
python 3DGeometry_IS.py
```

The graphical interface allows selection of:

- camera index;
- serial/COM port;
- image-output folder;
- settling delay;
- number of images;
- rotation direction.

A camera preview can be opened before acquisition.

When acquisition starts, a second live view allows representative exposure and gain adjustment before the automated rotation begins.

## Acquisition sequence

The corrected acquisition workflow is:

1. open the selected camera;
2. open the Arduino serial connection at 57600 baud;
3. display the camera-adjustment view;
4. capture the current angular position;
5. save the image;
6. command the requested angular increment;
7. wait for the Arduino to report completion of the motor movement;
8. wait for the user-defined mechanical settling delay;
9. capture the next angular position;
10. repeat until the requested number of unique images is acquired;
11. optionally return the stage to its initial orientation.

Waiting for the Arduino movement-completion message prevents the next image from being acquired only on the basis of a fixed time delay.

## Output

Images are saved using the naming convention:

```text
image_000.tiff
image_001.tiff
image_002.tiff
...
```

For the standard 101-image acquisition:

```text
image_000.tiff →   0.0°
image_001.tiff →   3.6°
...
image_100.tiff → 356.4°
```

The program creates the selected output directory if it does not already exist.

The TIFF files contain the frames returned by OpenCV. Camera pixel format and bit depth therefore depend on the camera, driver, and OpenCV backend configuration.

## Serial protocol

The current HEartLab stepper firmware uses:

```text
57600 baud
```

For each movement, the Python application transmits two numeric values:

```text
1
<angle>
```

For example:

```text
1
3.6000
```

The first value preserves compatibility with the current Arduino communication sequence and the second value is the requested relative angular movement.

The corrected Python implementation waits until the Arduino reports:

```text
Step Count:
```

which is printed after the firmware completes `runToPosition()`.

If the firmware communication protocol is changed, this application must be updated accordingly.

## Verification before use

Before an experimental acquisition:

- verify that the correct camera is selected;
- verify camera focus and field of view;
- verify exposure and gain behavior;
- verify the correct COM port;
- verify that Python and the Arduino firmware use the same baud rate;
- verify the stepper microstepping configuration;
- verify the mechanical transmission ratio;
- verify rotation direction;
- verify the angular increment;
- verify that 100 positions correspond to one complete revolution;
- verify that tubing and cables do not obstruct rotation;
- verify that TIFF files are written correctly;
- verify the expected number of output images.

> [!CAUTION]
> Camera communication, motor movement, angular calibration, exposure/gain settings, file output, and mechanical operation must be independently verified before experimental use.

See the repository-level [`DISCLAIMER.md`](../../DISCLAIMER.md).

## Known limitations

The current implementation:

- searches a limited range of OpenCV camera indices;
- assumes one camera is used for this acquisition;
- uses OpenCV's generic exposure and gain properties;
- does not automatically determine camera-specific valid control ranges;
- does not embed acquisition metadata into the TIFF filenames;
- does not perform 3D reconstruction;
- does not guarantee compatibility with cameras other than the tested HEartLab Imaging Source USB setup.

The camera-preview window should be closed before starting the acquisition if the operating system or driver does not permit the same camera to be opened by multiple application instances.

## Source file

The main application is:

[`3DGeometry_IS.py`](3DGeometry_IS.py)

The version provided here includes corrections to the original implementation for image-count logic, serial-port compatibility, motor-completion handling, error handling, device-list validation, and resource cleanup.

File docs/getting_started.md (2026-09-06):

# Getting Started

This guide provides a high-level workflow for reproducing, adapting, or operating components of the HEartLab multimodal mapping platform.

The platform is modular. A laboratory does **not** need to reproduce every subsystem or experimental configuration described in this repository. The recommended approach is to first select the preparation and scientific objective, then select the required platform modules and experiment-specific protocols, and finally assemble and validate those components before use with a biological preparation.

> **Documentation status:** This repository is under active development. Detailed bills of materials, wiring diagrams, calibration procedures, and configuration-specific assembly instructions are being added progressively. Where detailed instructions are not yet available, consult the corresponding subsystem README together with the associated publication, or contact the authors for a more detailed explanation.

---

## 1. Choose the experimental configuration

The platform has been implemented in three main configurations.

### Small-heart whole-organ configuration

Designed for Langendorff-perfused rabbit hearts.

Available modules can include:

- Langendorff perfusion;
- physiological monitoring;
- panoramic optical mapping;
- epicardial contact-electrical mapping using multi-electrode arrays (MEAs);
- torso-tank electrical mapping;
- electrical stimulation;
- hardware synchronization;
- experiment control and logging;
- experiment-specific 3D reconstruction.

### Large-heart whole-organ configuration

Designed for intact porcine and human ex vivo hearts.

Available modules can include:

- independent coronary perfusion;
- physiological monitoring;
- optical mapping;
- torso-tank electrical mapping;
- electrical stimulation when required by the experimental protocol;
- hardware synchronization;
- experiment control and logging;
- mechanical support adapted to large preparations;
- experiment-specific 3D reconstruction.

### Large-heart epi-endo configuration

Designed for isolated perfused ventricular-wall preparations.

Available modules can include:

- coronary perfusion of the isolated preparation;
- physiological monitoring;
- simultaneous epicardial and endocardial optical mapping;
- paired epicardial and endocardial contact-electrical mapping;
- mirror-assisted optical access;
- electrical stimulation when required by the experimental protocol;
- hardware synchronization;
- experiment control and logging.

---

## 2. Define the scientific objective

The experimental configuration defines the available platform modules, but the scientific objective determines which of those modules and protocols are required in a particular experiment.

Examples of experiment-specific decisions include:

- whether torso-tank recordings are required;
- pacing site and pacing protocol;
- whether arrhythmia induction is required;
- whether pharmacological interventions are used;
- whether AV-node ablation is performed;
- whether 3D reconstruction is required;
- whether tissue is collected for subsequent analysis.

Therefore, do not interpret the documentation as a single mandatory protocol that must be followed identically for every experiment.

Representative experimental protocols are available in [`protocols/`](protocols/).

---

## 3. Select the required platform modules

After defining the experimental objective, identify the required modules.

| Module | Function | Repository location |
|---|---|---|
| Perfusion | Maintains the ex vivo cardiac preparation under controlled conditions | [`../hardware/`](../hardware/) |
| Physiological monitoring | Measures perfusion pressure, flow, and temperature | [`../hardware/`](../hardware/) and [`../firmware/sensors/`](../firmware/sensors/) |
| Optical mapping | Records voltage-sensitive fluorescence from cardiac surfaces | [`../hardware/`](../hardware/) |
| Contact electrical mapping | Records local extracellular electrograms using MEAs | [`../hardware/`](../hardware/) |
| Torso-tank mapping | Records cardiac potentials from electrodes surrounding a conductive volume | [`../hardware/`](../hardware/) |
| Electrical stimulation | Provides pacing and arrhythmia-induction stimuli | [`../hardware/`](../hardware/) |
| Hardware synchronization | Provides a common timing reference to independent acquisition systems | [`../firmware/synchronization_controller/`](../firmware/synchronization_controller/) |
| Sensor communication | Transfers physiological measurements from sensor nodes to the experimental computer | [`../firmware/sensors/`](../firmware/sensors/) and [`../firmware/gateway/`](../firmware/gateway/) |
| Experiment control | Coordinates monitoring, stimulation, synchronization, metadata, and experimental events | [`../software/experiment_control/`](../software/experiment_control/) |
| Mechanical components | Supports the preparation and custom experimental interfaces | [`../cad/`](../cad/) |

The exact combination of modules depends on the preparation and experimental objective.

---

## 4. Obtain the repository

Clone the repository using Git:

```bash
git clone https://github.com/HEartLab-ufabc/HEartLab-Multimodal-Mapping.git
cd HEartLab-Multimodal-Mapping
```

For experiments intended to reproduce a published implementation, use the tagged release identified in the publication or repository citation information rather than the continuously updated `main` branch.

---

## 5. Review hardware and fabrication requirements

Before assembling any subsystem, identify:

- commercial components that must be obtained;
- custom mechanical parts that must be fabricated;
- custom electronic interfaces that must be assembled;
- required acquisition equipment;
- required sensors and microcontrollers;
- required power supplies and communication interfaces.

Hardware documentation is located in:

[`../hardware/`](../hardware/)

Mechanical design files are located in:

[`../cad/`](../cad/)

Subsystem bills of materials and component information are provided under [`../hardware/`](../hardware/).

---

## 6. Review the relevant experimental protocols

Protocols are organized separately from hardware and software documentation because they can vary according to experimental goal.

Representative protocols, planning documents, recording forms, and experimental examples are available in:

[`protocols/`](protocols/)

The files document implementations used in HEartLab experiments and are not intended to define a single mandatory workflow for all preparations.

Before using a protocol, verify that it corresponds to the intended preparation, experiment, ethical approval, and current validated laboratory procedure.

---

## 7. Fabricate the required custom components

Custom mechanical components should be fabricated according to files provided in the `cad/` directory.

Depending on the component, the repository may provide:

- editable CAD source files;
- STEP or other neutral CAD formats;
- STL files for additive manufacturing;
- dimensioned drawings;
- fabrication notes.

Before fabrication, verify:

- file units;
- critical dimensions;
- material requirements;
- tolerances;
- expected preparation dimensions;
- compatibility with locally available equipment.

The supplied designs represent implementations used in HEartLab and may require adaptation for different tanks, cameras, cannulae, electrodes, or preparation sizes.

---

## 8. Assemble the physiological-monitoring network

The current embedded monitoring architecture uses independent sensor nodes associated with active perfusion lines.

The general communication path is:

```text
Flow / temperature sensor ─┐
                           │
Pressure sensor ───────────┼──> Sensor node ── wireless ──> Gateway ── USB ──> Computer
                           │
Other local sensors ───────┘
```

The current implementation includes:

- Arduino Nano-based sensor nodes;
- nRF24L01 wireless communication;
- an ESP32-S3 gateway connected to the experimental computer.

Sensor-node firmware:

[`../firmware/sensors/`](../firmware/sensors/)

Gateway firmware:

[`../firmware/gateway/`](../firmware/gateway/)

Before uploading firmware, verify the documented:

- board type;
- sensor model;
- pin assignments;
- node identifier;
- wireless configuration;
- required libraries;
- communication settings.

Do not assume that configuration values from one node or experimental setup are appropriate for another.

---

## 9. Configure the synchronization controller

The current synchronization implementation uses a Teensy 4.1 timing controller.

Firmware is located in:

[`../firmware/synchronization_controller/`](../firmware/synchronization_controller/)

The synchronization controller provides hardware timing signals used to align independent recording systems and experimental events.

Before connecting acquisition equipment, verify:

- accepted trigger voltage;
- trigger polarity;
- pulse-width requirements;
- input impedance;
- grounding arrangement;
- whether galvanic isolation is required.

Hardware trigger requirements should always be checked against the documentation of the connected acquisition device.

---

## 10. Install the experimental-control software

The experimental-control application is located in:

[`../software/experiment_control/`](../software/experiment_control/)

The software is used to coordinate several platform functions, including:

- experimental session organization;
- physiological monitoring;
- stimulation control;
- synchronization-related operations;
- recording coordination;
- metadata entry;
- event logging.

Follow the software README for the tested operating system, Python version, package dependencies, and serial-interface configuration.

The application should be tested with the embedded hardware before use during an experiment.

---

## 11. Validate each subsystem independently

Before combining the system with a biological preparation, validate each required module independently.

### Perfusion

Confirm:

- correct flow direction;
- absence of leaks;
- absence of trapped air;
- stable temperature;
- stable pressure;
- expected flow range.

### Physiological monitoring

Confirm:

- each sensor is detected;
- readings are physically plausible;
- node identifiers are correct;
- wireless packets are received consistently;
- measurements appear correctly in the control software.

### Electrical stimulation

Confirm:

- output is disabled at startup;
- pulse timing is correct;
- output amplitude is verified using an appropriate test load;
- trigger behavior is correct;
- no unintended output occurs during connection or reset.

### Synchronization

Confirm:

- the expected synchronization signal is generated;
- all intended acquisition systems receive the signal;
- frequency and pulse width are correct;
- trigger edges are temporally aligned within the requirements of the experiment.

An oscilloscope or logic analyzer is strongly recommended for synchronization verification.

### Optical and electrical acquisition

Confirm:

- acquisition can be started and stopped reliably;
- trigger configuration is correct;
- signals are recorded using the expected sampling settings;
- reference and grounding arrangements are correct.

---

## 12. Perform an integrated bench test

After individual subsystems have been validated, test the integrated system without a biological preparation.

A recommended bench test includes:

1. power all required devices;
2. connect the sensor nodes and gateway;
3. verify sensor communication;
4. start the experimental-control software;
5. verify the synchronization output;
6. connect acquisition-system trigger inputs;
7. execute a short test recording;
8. generate representative stimulation events using an appropriate test load;
9. confirm that events are correctly logged;
10. confirm that recorded signals can be temporally aligned.

Resolve communication, timing, or stimulation issues before beginning an ex vivo experiment.

---

## 13. Prepare an experiment-specific plan

Before each experiment, document:

- preparation type;
- scientific objective;
- selected mapping modalities;
- selected stimulation protocol;
- optional pharmacological or electrophysiological interventions;
- required solutions;
- required equipment;
- intended recording sequence;
- tissue-processing requirements, if any;
- criteria for optional procedures such as 3D reconstruction.

Use the representative experiment-planning documents in [`protocols/`](protocols/) as a basis for recording the experiment-specific configuration.

---

## 14. Pre-experiment verification

Immediately before an experiment, verify at minimum:

- [ ] required firmware versions are documented;
- [ ] the correct experimental-control software version is being used;
- [ ] sensor nodes have the correct identifiers;
- [ ] physiological sensors are operating;
- [ ] perfusion tubing is correctly connected and primed;
- [ ] no air remains in critical perfusion-line sections;
- [ ] temperature control is operating;
- [ ] pressure and flow readings are plausible;
- [ ] synchronization outputs have been verified;
- [ ] acquisition systems are receiving the intended hardware trigger;
- [ ] stimulation output has been tested on an appropriate load;
- [ ] cameras and electrical acquisition systems have sufficient storage space;
- [ ] experimental metadata and output directories are configured;
- [ ] all required custom hardware is mechanically secure;
- [ ] the experiment-specific protocol and required solutions have been confirmed.

Configuration-specific checklists may contain additional requirements.

---

## 15. Run and document the experiment

During each experiment, preserve enough information to identify:

- preparation and experimental configuration;
- scientific objective;
- platform modules used;
- firmware versions;
- experimental-control software version;
- acquisition settings;
- stimulation protocols;
- sensor configuration;
- pharmacological or procedural interventions;
- recording identifiers;
- deviations from the planned protocol.

Where possible, use Git release or commit identifiers to associate experimental data with the exact software and firmware revision used for acquisition.

---

## 16. After the experiment

After acquisition:

1. verify that all expected files were saved;
2. preserve the experiment log;
3. back up raw optical and electrical data;
4. preserve physiological-monitoring records;
5. preserve configuration and stimulation information;
6. record deviations from the planned protocol;
7. record hardware or software issues encountered during the experiment;
8. associate the dataset with the corresponding repository release or Git commit.

Raw experimental data should be preserved independently of processed or exported data.

---

## Reproducibility and versioning

The `main` branch represents continued platform development.

For published work, a tagged release should identify the exact version of:

- firmware;
- experimental-control software;
- hardware documentation;
- CAD files;
- protocol documentation;
- configuration information.

When reproducing an experiment, use the release specified by the corresponding publication whenever possible.

---

## Safety and intended use

The HEartLab platform is intended for experimental research with ex vivo cardiac preparations.

It is **not a medical device** and has not been designed, validated, or approved for clinical diagnosis, treatment, patient monitoring, or direct use in humans.

Users are responsible for evaluating the electrical, mechanical, biological, chemical, and laboratory safety requirements applicable to their implementation and institution.

---

## Next steps

After completing this guide, consult the subsystem-specific documentation for detailed assembly, configuration, calibration, and operation instructions.

Start with:

- [`../hardware/`](../hardware/) for physical and electronic subsystems;
- [`../firmware/`](../firmware/) for embedded controllers;
- [`../software/`](../software/) for the experimental-control application;
- [`../cad/`](../cad/) for custom mechanical designs;
- [`protocols/`](protocols/) for experimental protocol documentation.

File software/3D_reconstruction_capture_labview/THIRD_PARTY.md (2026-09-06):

# Third-Party Software and Components

This document identifies third-party material included in or required by the HEartLab Multimodal Mapping repository.

Third-party material remains subject to its original copyright and license terms. The license applied to original HEartLab material does not override the license of third-party components.

## RHYTHM open-source imaging toolkit

**Included component:** `software/3D_reconstruction_capture_labview/saveNumberedImage.vi`

The VI was obtained from the RHYTHM open-source imaging toolkit and is used as part of the HEartLab LabVIEW workflow for rotational image acquisition.

**Source project:** `https://github.com/optocardiography/RHYTHM-2.0`

**License:** MIT License

**Original copyright notice:** Copyright (c) 2018 optocardiography

A copy of the applicable MIT license is included as:

`software/3D_reconstruction_capture_labview/RHYTHM_LICENSE.txt`

**Citation:** Gloschat C. et al. *RHYTHM: An Open Source Imaging Toolkit for Cardiac Panoramic Optical Mapping*. Scientific Reports. 2018;8:2921.

The RHYTHM-derived VI retains the original copyright and license notice. Any HEartLab modifications remain subject to the applicable RHYTHM/MIT terms.

## Commercial and proprietary dependencies

The repository may also reference commercial hardware, drivers, SDKs, or proprietary software required to reproduce specific experimental configurations. These components are not redistributed unless their licenses explicitly allow redistribution.

Examples may include LabVIEW and National Instruments components, EVT camera drivers/software, manufacturer camera SDKs, commercial acquisition software, and commercial CAD software.

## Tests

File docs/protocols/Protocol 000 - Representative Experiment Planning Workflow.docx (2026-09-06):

# Protocol 000: Experiment Planning

HEartLab, 2025.

# Experiment information

Date:

Time:

Experiment nº:

People:

# Pre-experiment Conference

- Check Day before sheet (Must be completed)
- Solutions preparation (check the Protocol 001)
  - Sucrose Solution: 6 L (Since the beginning)
  - Cardioplegia: 500 ml
  - Krebs-Henseleit Solution: 10L(Langendorff )
  - Check hardware
  - Optical cameras’ position.
  - MEAs in the right location.
  - The stimulator checking.
  - Physical space in the computer
- Check the software and recording systems
  - Check the number of electrodes in Open Ephys
  - Check if the StreamPix9 recording system is working properly
  - Check the TTL signal and camera trigger
  - Check the LabVIEW program for 3D reconstruction
  - Check pacing stimulator and software
- Fill and position the TANK next to the setup
- Check the temperature of the solutions and start recirculating
  - Langendorf Water Bath 39.5 ºC
  - Tank Water Bath - 43.5 ºC important: let this temperature set, avoiding precipitation
  - Check one by one each electrode and try to measure the solution impedance
- Start oxygenation of the solutions (At least 10 min before heart connection)
- Remove bubbles from the system
- Start OBS recording

# Experiment Procedures

## Heart stabilisation

- Euthanasia and heart extraction Protocol: Euthanasia
- Put the extracted heart inside one beaker with the solution previously
- Cannulate the heart with the special reference cannula and connect to the Langendorff system. Important: Position not too deep in the aorta
- Cleaning the heart: Remove the lung tissue surrounding the pulmonary veins. Separate the pulmonary artery from the aorta and insert a thin tube to prevent blockage.
- Wait at least 10 minutes for stabilisation
- Balloon insertion in the atria.
- Oriented the heart as follow, LA=cam A-MEA3; RA=cam B-MEA1; V=cam C-MEA2;

## Recording reference for Sinus

- Starts OBS recording
- Recording electrical signal only - Without Dye or Blebbistatin

## Dye Administration and Heart Movement Blockage

- Dye Infusion - Protocol 005: Dye Infusion
- Remember to let the air out of the ballons during infusion and to let the air in after infusion
- Recording electrical SN.
- Blebbistatin Infusion - Protocol 006: Movement Suppression
- Wait for 15 minutes for stabilisation
- Record optical and electrical SN
- Test pacing before submerging into the tank

## Tank Positioning

- Put the tank in the middle of the setup
- Put the heart in the tank full of Sucrose solution and preheated to 37 degrees.
- Orient the heart as follow, LA=cam A-MEA3; RA=cam B-MEA1; V=cam C-MEA2;

## Cardiac Baseline Mapping

- Record optical and electrical SN

## Pacing

- Position the pacing electrode over the LA - register the place.
- Record Pacing 350, 300, 250ms. (Two recording of 10 seconds each)

## Baseline Effective Refractory Period (ERP)

- Program the stimulation software with:
  - S1= 250ms (8 pulses)
  - S2= starting in 220ms (1 pulses) and decreasing by 10ms, decrease by 2ms close to the ERP
  - Important: Identify the longest S1S2 coupling interval with loss of AV-nodal conduction. This interval corresponds to the AVNERP (AV node effective refractory period)
- Record the ERP and one before that

## Drugs protocol

- Dilute 1ml of a 1mM Carbachol solution (1 Eppendorf) in 999 ml of nutrient solution.
- Dilute 25 ml of Concentrated Blebbistatin (68 uM at 30°C) to that 1L solution.
  - Following the same protocol for “Motion Suppression”.
- Add the eluted 1uM carbachol solution into the reservoir with a low level of solution.
- Wait for up to 30 seconds and repeat Baseline Effective Refractory Period (ERP)
- Before the electrical stimulation, we need to see a consistent decrease in heart rate rhythm.

## Arrhythmia Induction

We start with the atria if we do not have results we try to induce ventricle arrhythmia.

- Burst Protocol
  - Duration: 2s each burst
  - Pulse Width: 2ms
  - Cycle Length: 20ms (50Hz)
  - Number of Cycles: 8
  - Interval between cycles: 10s
  - Intensity: Maximum possible
- Wait ten minutes between each protocol
- Repeat a maximum of 5 times the protocol

## 3D Generation

- Remove the CO2 supply and disconnect the Langendorff system
- Identify the camera to be used in 3D reconstruction in the sheet with the figure
- Make the heart 3D mapping of the heart in the tank
- Make the 3D calibration map with the tank
- Remove the tank from the setup
- Make the 3D calibration map without the tank
- Make the 3D mapping of the heart without the tank

HEartLab group Version 06

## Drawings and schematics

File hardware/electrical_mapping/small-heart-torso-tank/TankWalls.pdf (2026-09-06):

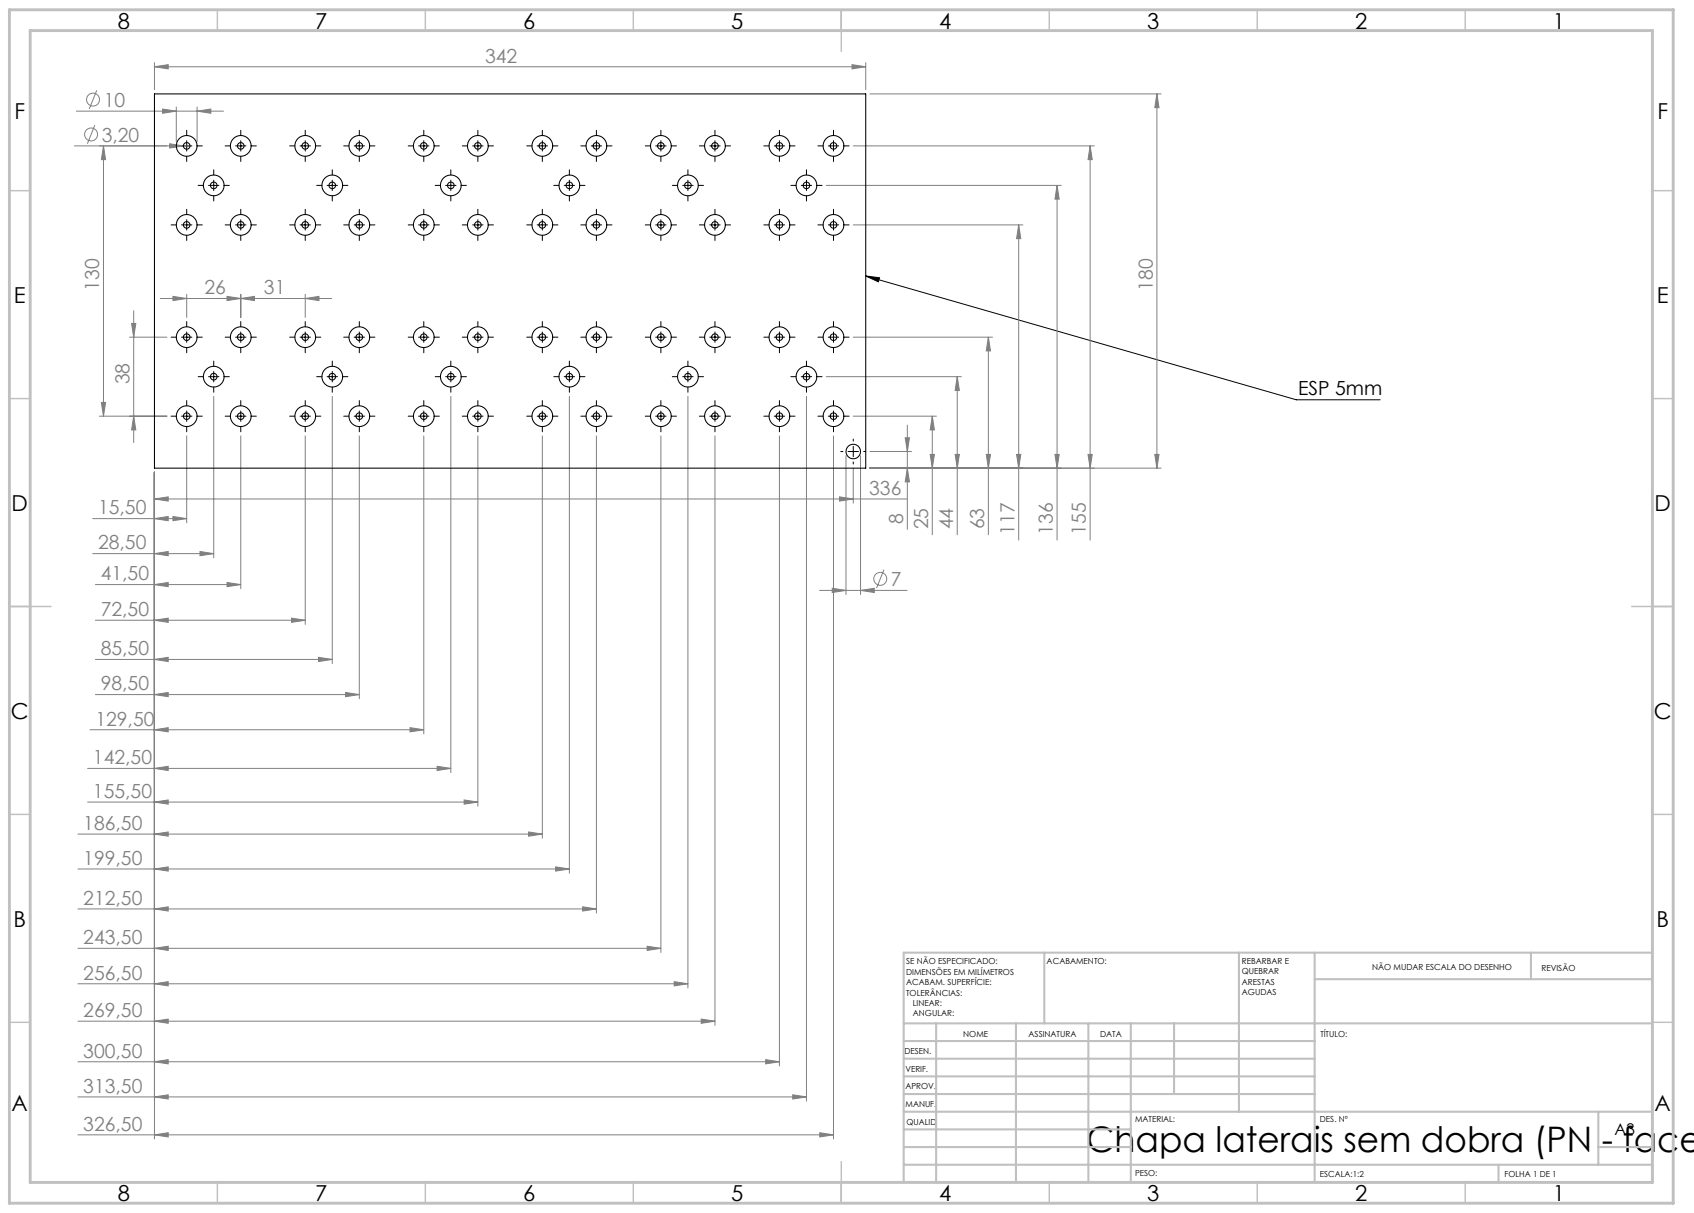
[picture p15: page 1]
ESP 5mm; ACABAMENTO:; REBARBAR E; NÃO MUDAR ESCALA DO DESENHO; REVISÃO; ESCALA:1:2; FOLHA 1 DE 1

SE NÃO ESPECIFICADO:
DIMENSÕES EM MILÍMETROS
ACABAM. SUPERFÍCIE:
TOLERÂNCIAS:
LINEAR:
ANGULAR:

NOME | ASSINATURA | DATA | | | | TÍTULO:

DESEN.
VERIF.
APROV.
MANUF.
QUALID | | | | MATERIAL: | DES. Nº | A3

Chapa laterais sem dobra (PN - face interna)

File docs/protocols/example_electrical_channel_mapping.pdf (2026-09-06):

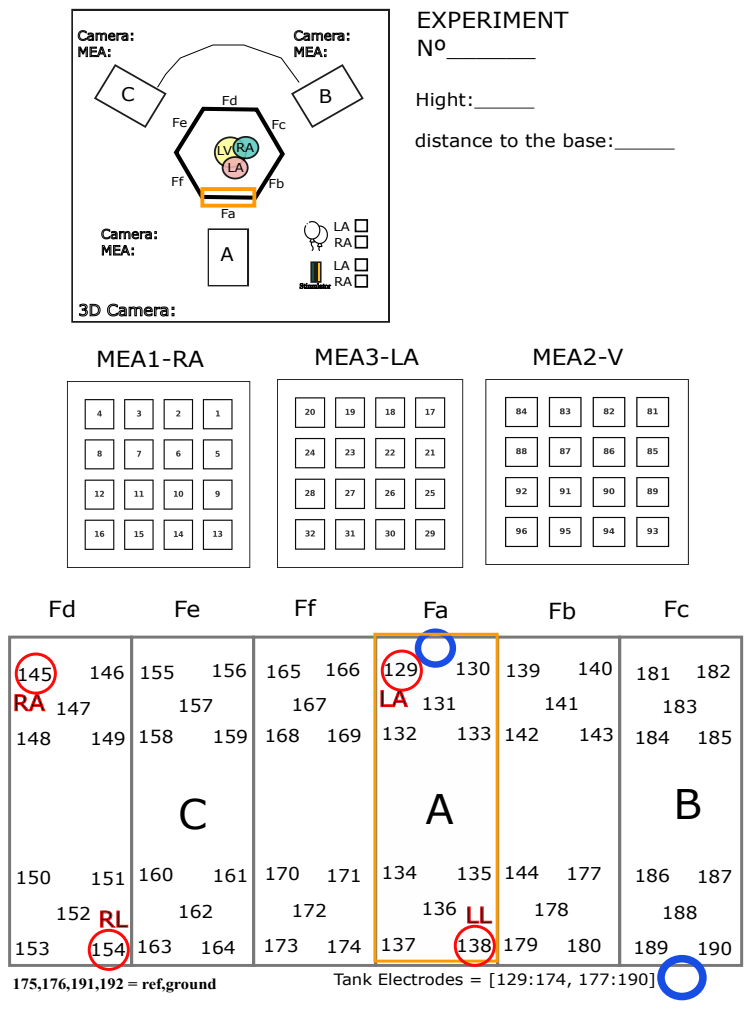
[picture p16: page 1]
175,176,191,192 = ref,ground; MEA1-RA; MEA3-LA; MEA2-V; EXPERIMENT Nº______; Hight:_____; Tank Electrodes = [129:174, 177:190]

distance to the base:_____

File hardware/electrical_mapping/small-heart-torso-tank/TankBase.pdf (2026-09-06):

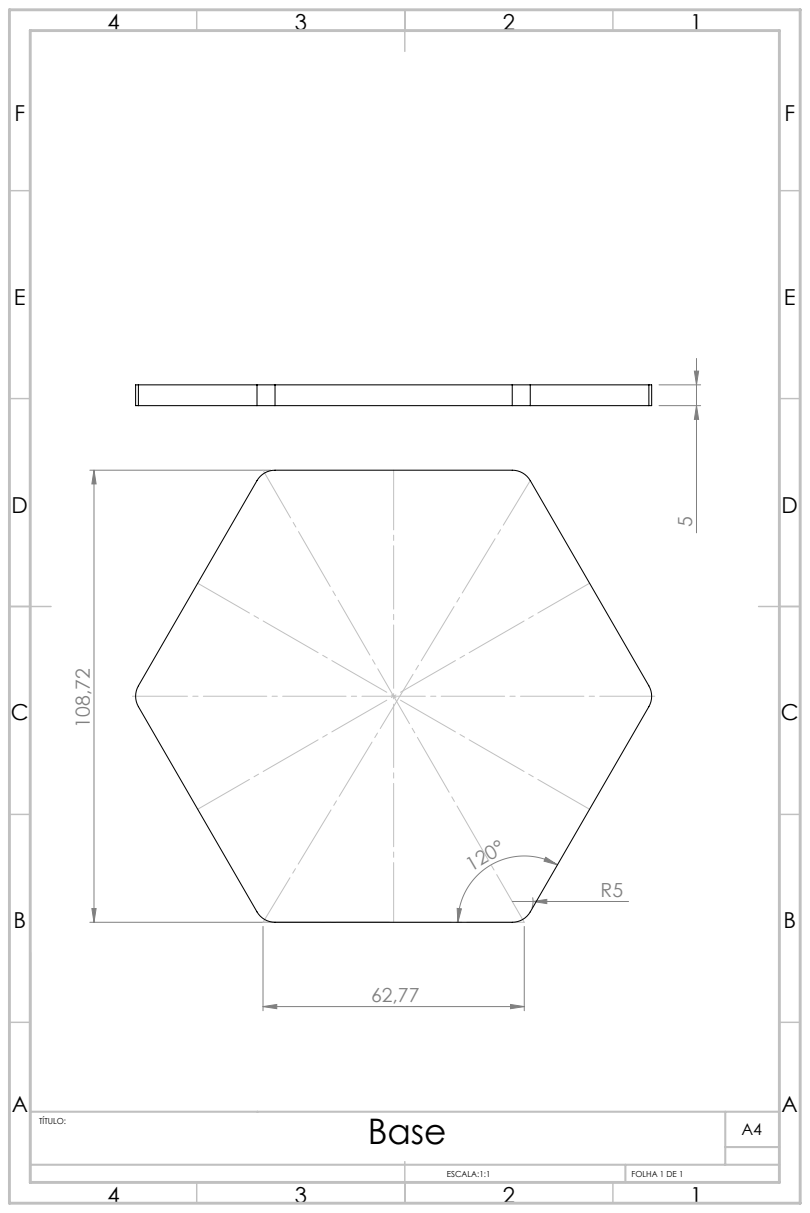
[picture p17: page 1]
ESCALA:1:1; FOLHA 1 DE 1

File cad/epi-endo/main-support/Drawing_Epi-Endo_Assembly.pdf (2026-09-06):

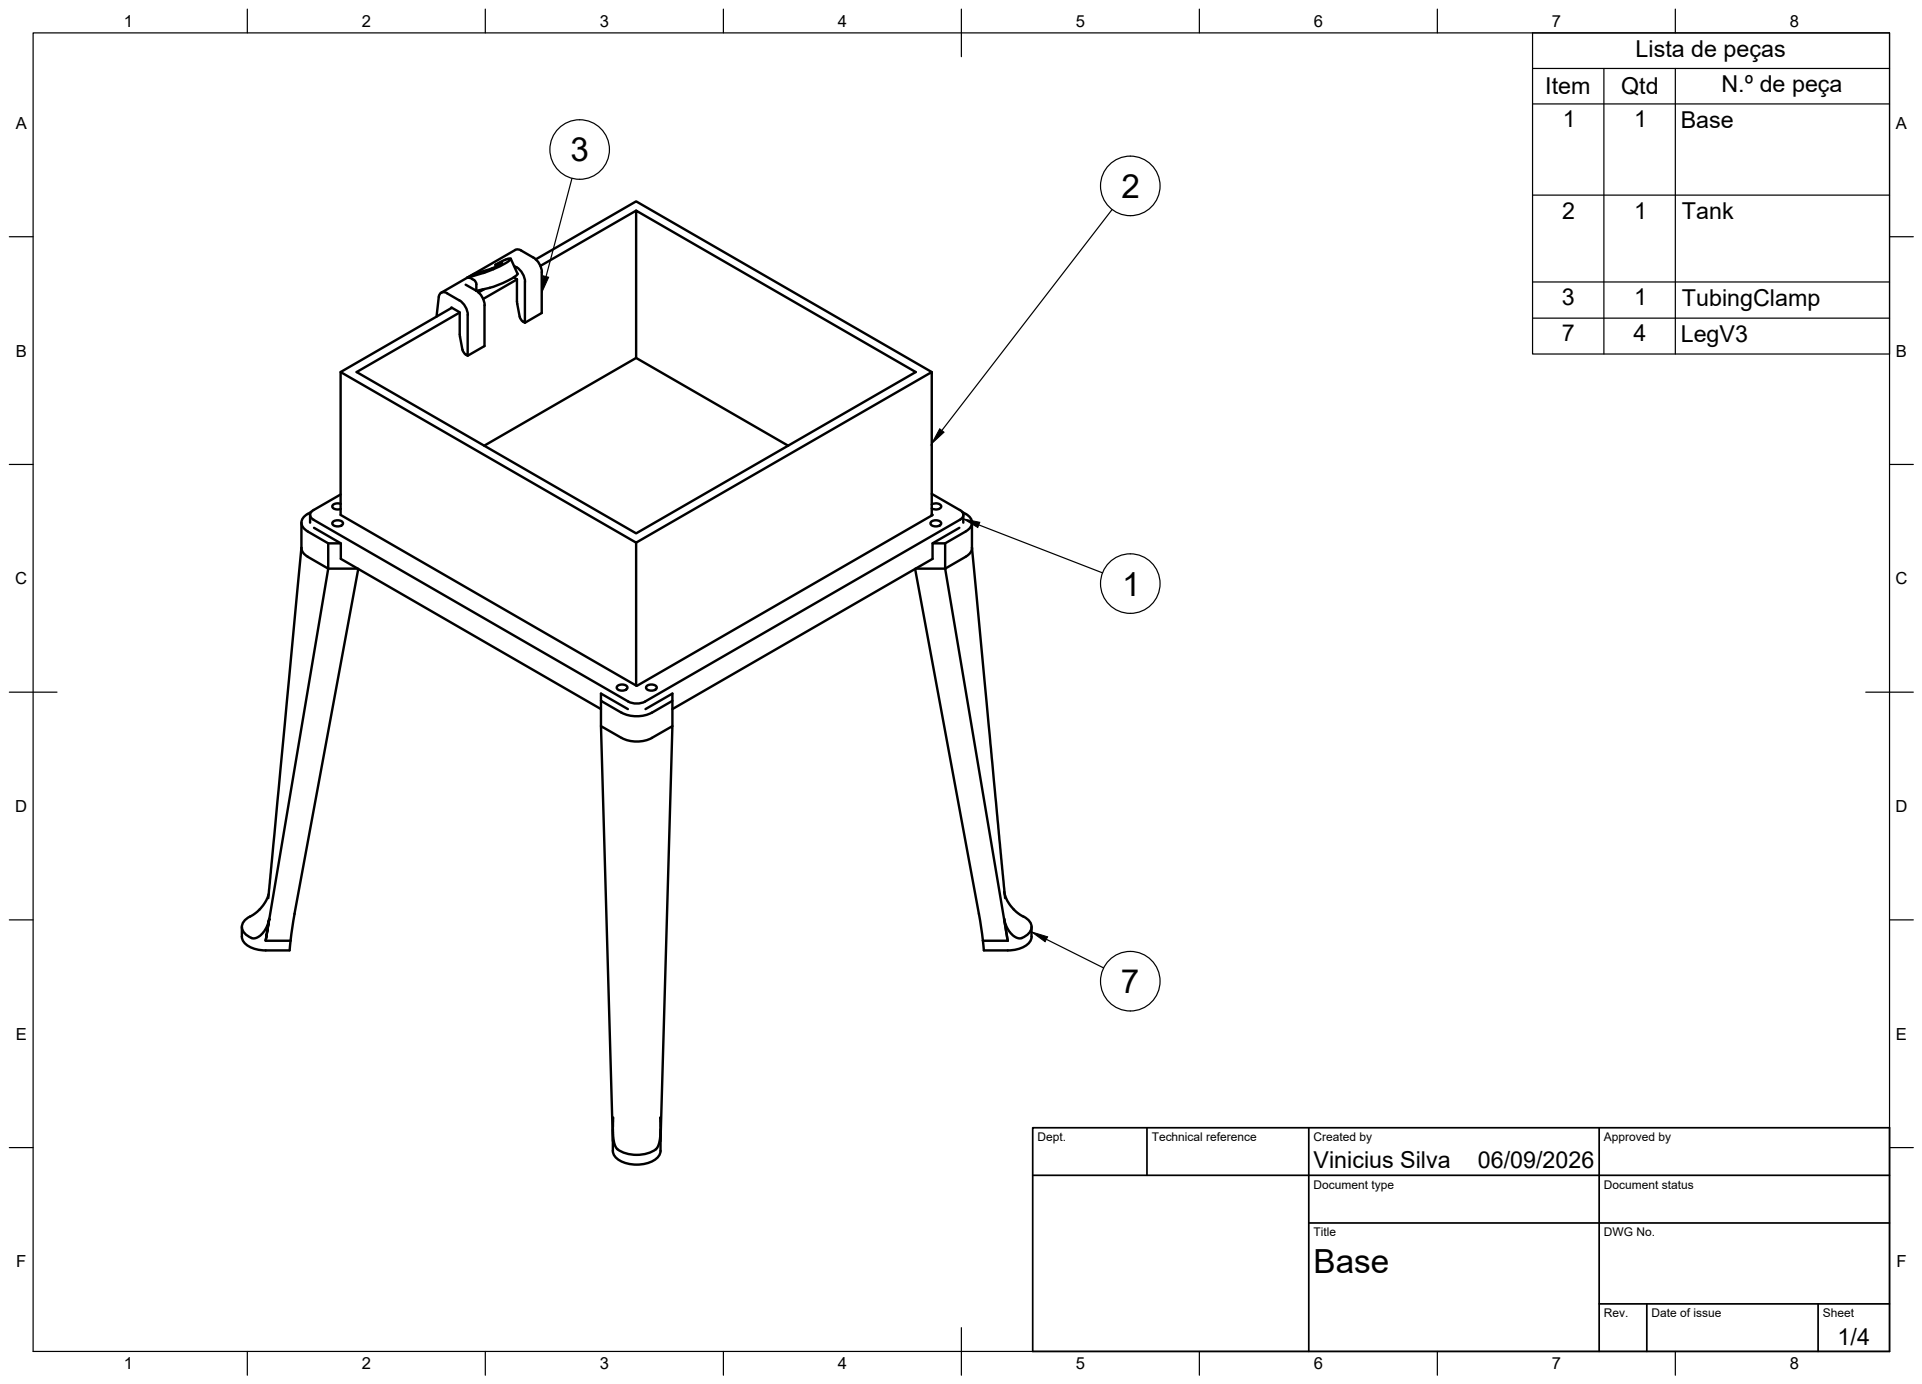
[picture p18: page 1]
Title; DWG No.; Rev.; Date of issue; Sheet

Lista de peças

Item | Qtd | N.º de peça
1 | 1 | Base

2 | 1 | Tank

3 | 1 | TubingClamp
7 | 4 | LegV3

Dept. | Technical reference | Created by Vinicius Silva 06/09/2026 | Approved by

Document type | Document status

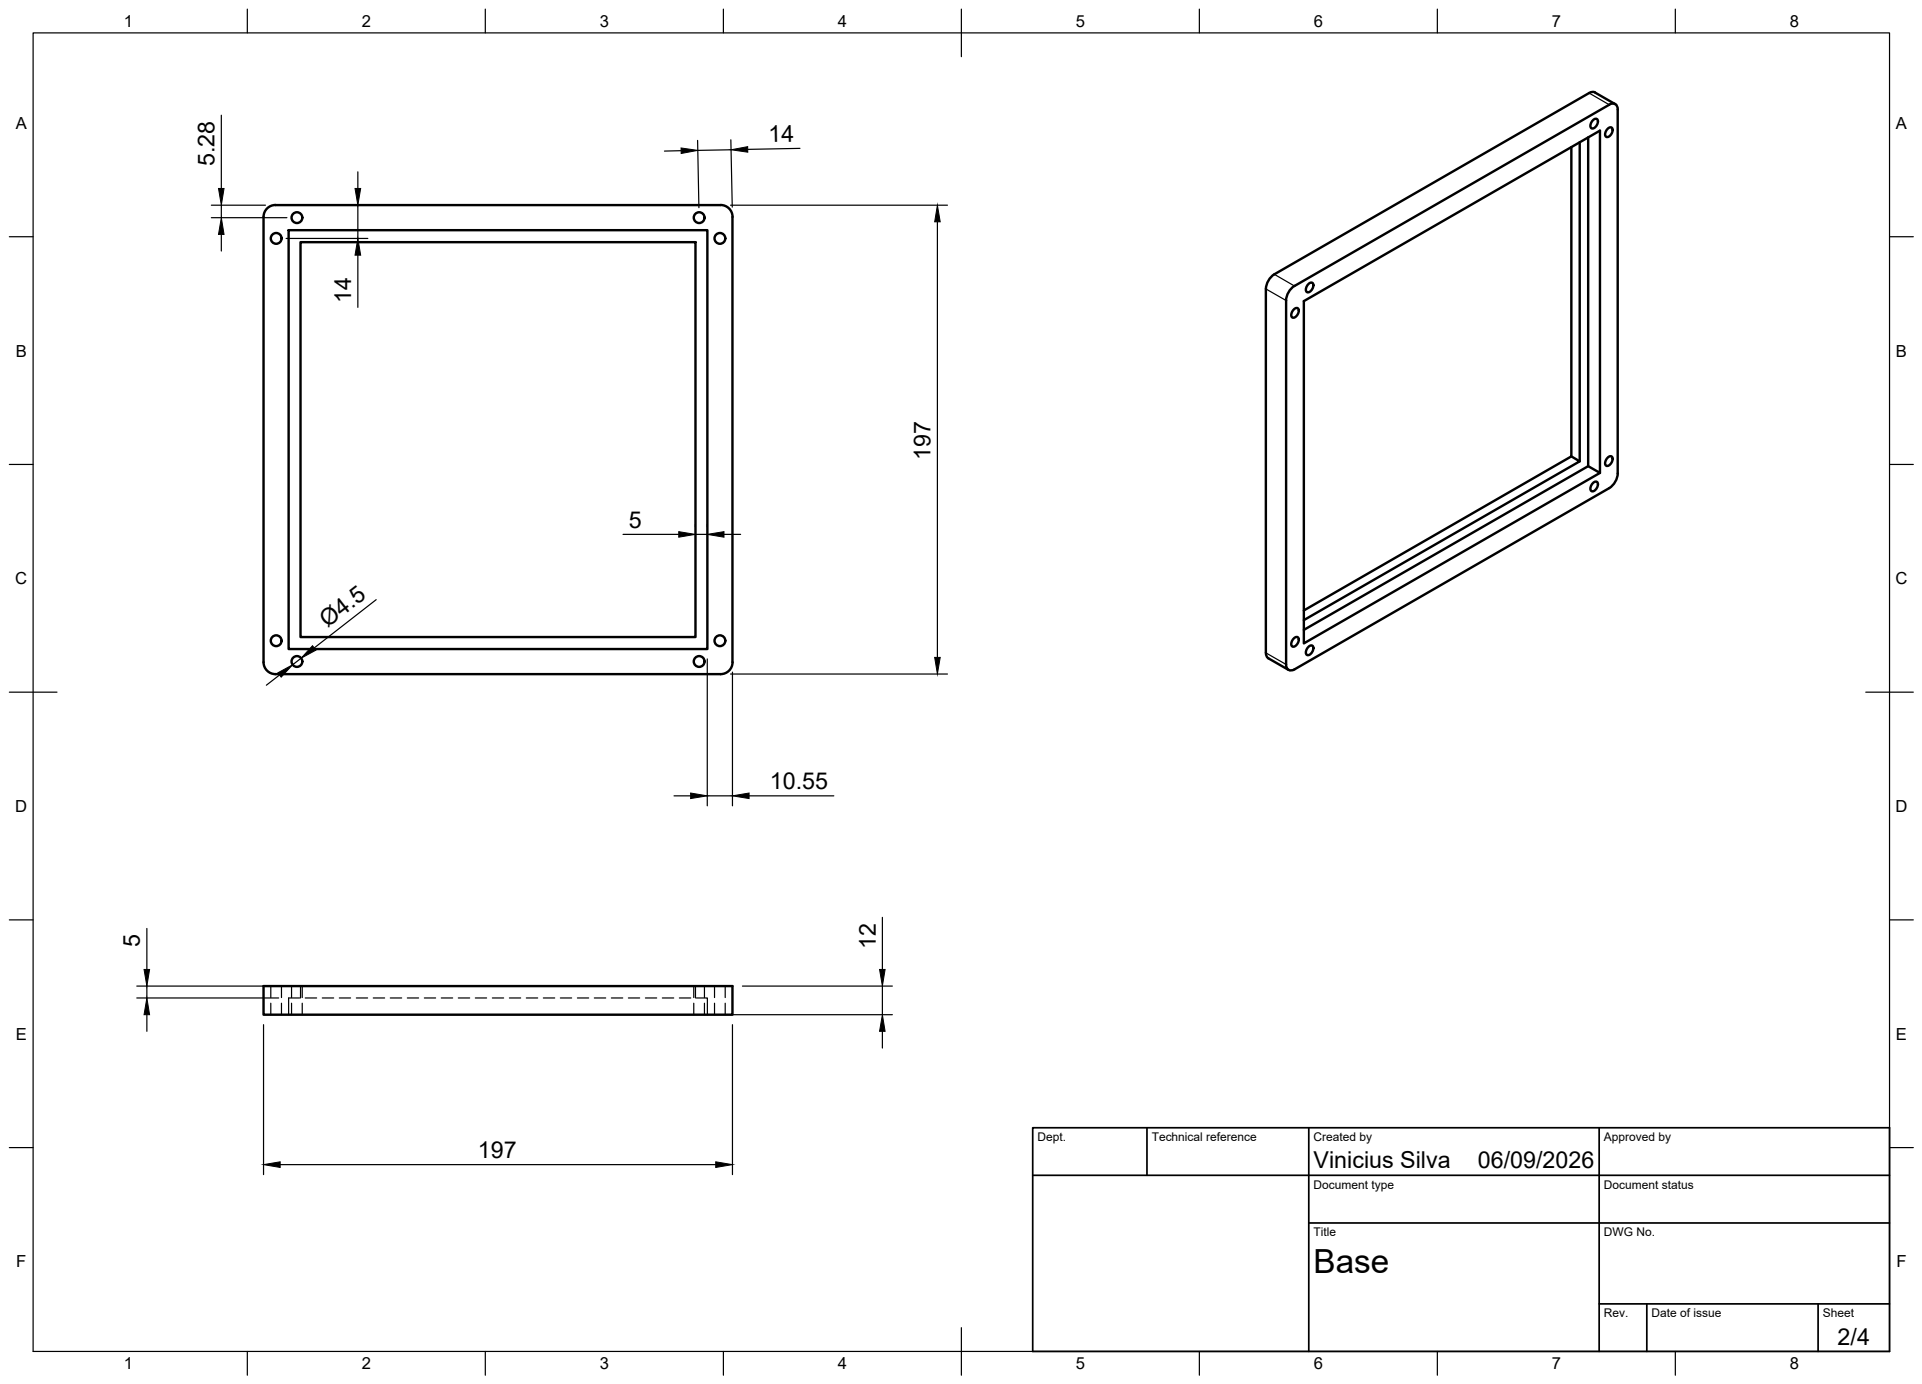
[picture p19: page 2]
Title; DWG No.; Vinicius Silva 197

Dept. | Technical reference | Created by 06/09/2026 | Approved by

Document type | Document status

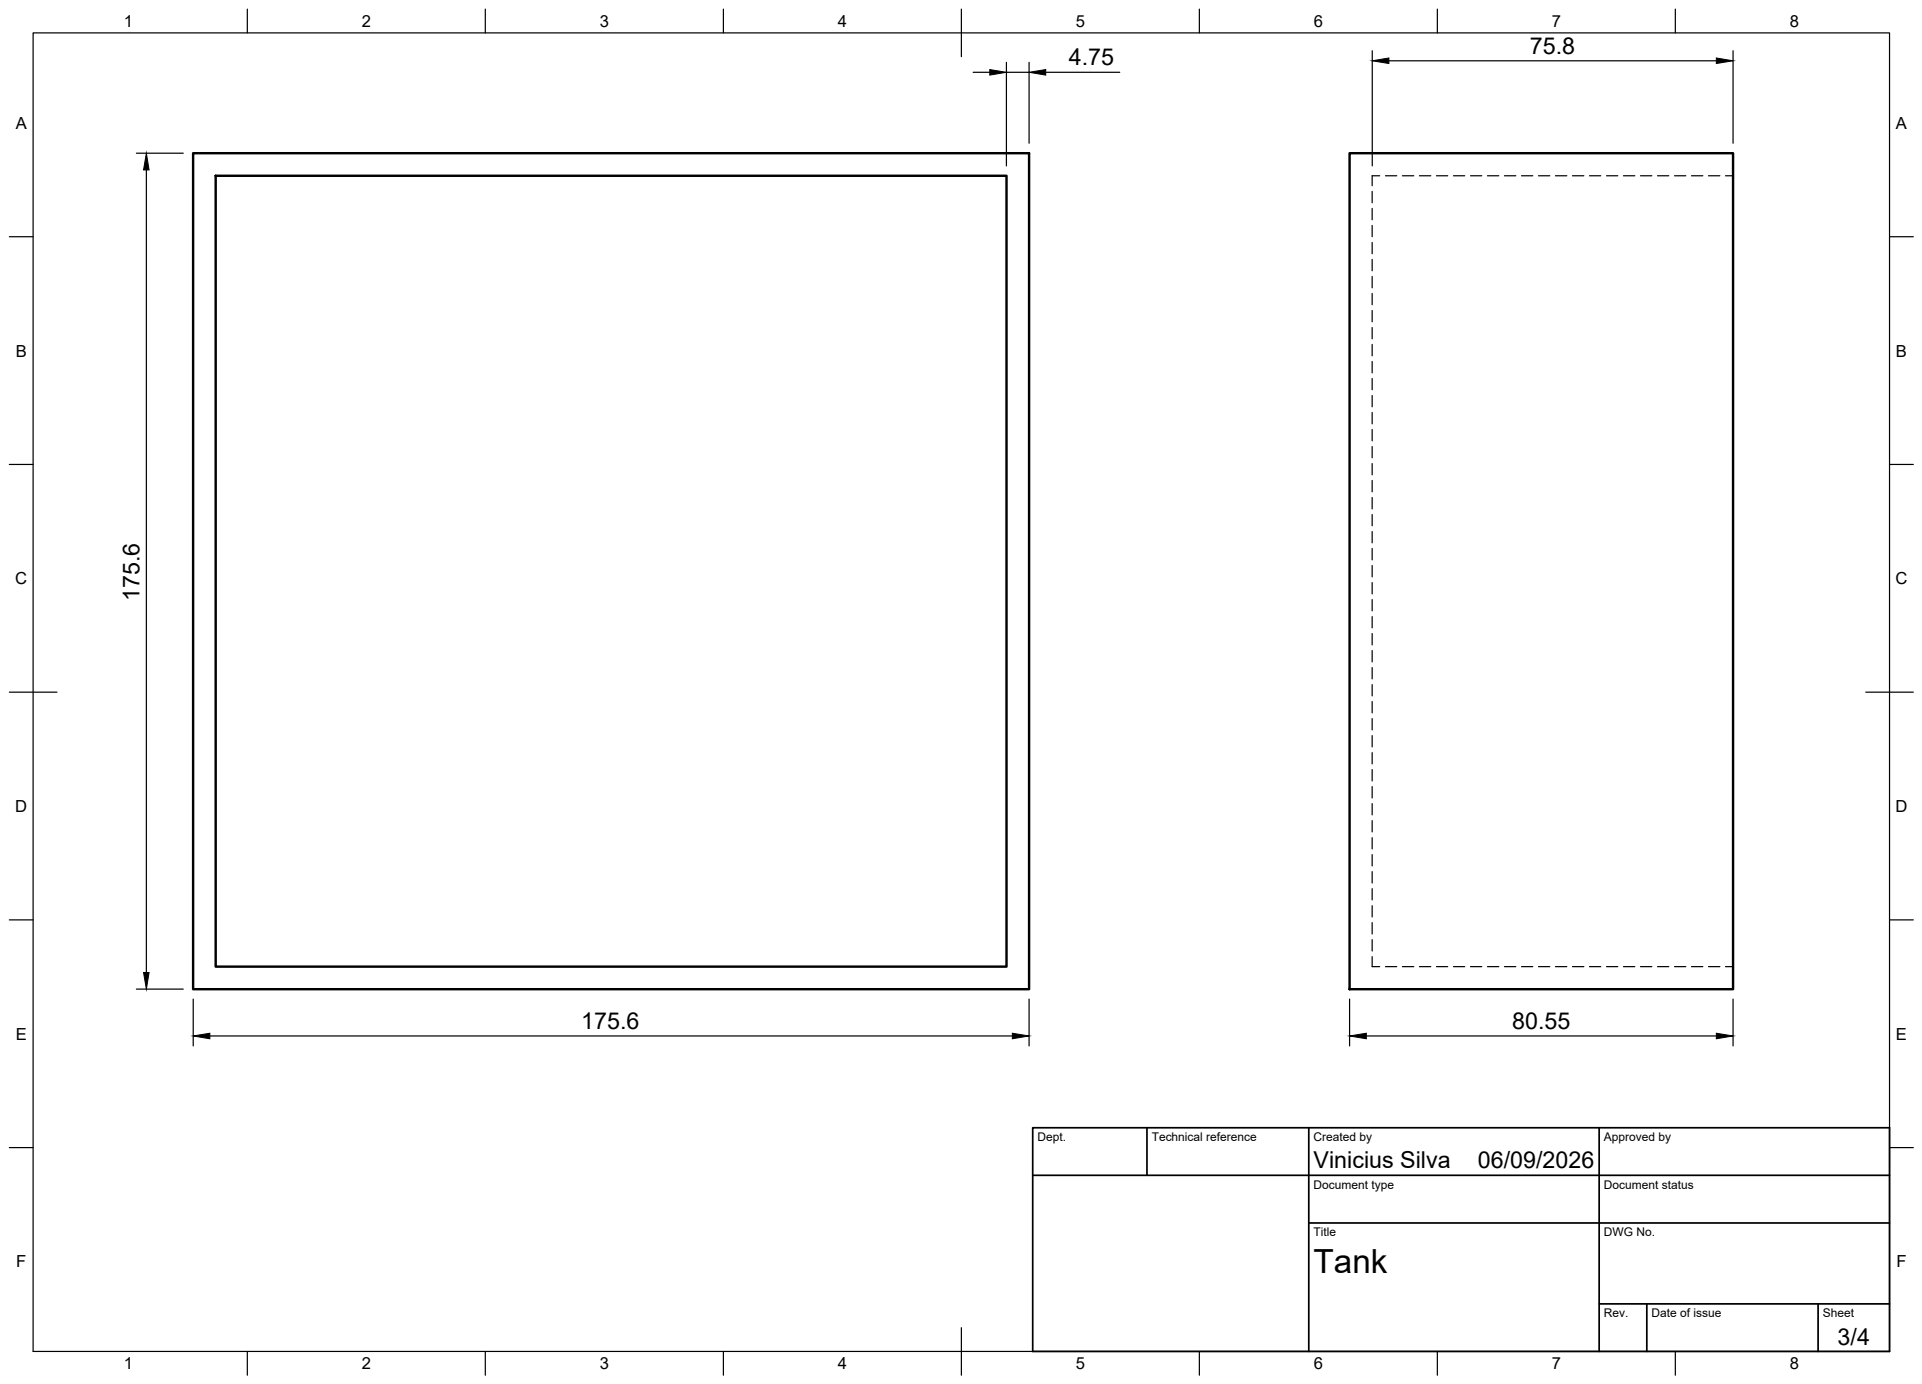
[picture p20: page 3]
Title; DWG No.

Dept. | Technical reference | Created by Vinicius Silva 06/09/2026 | Approved by

Document type | Document status

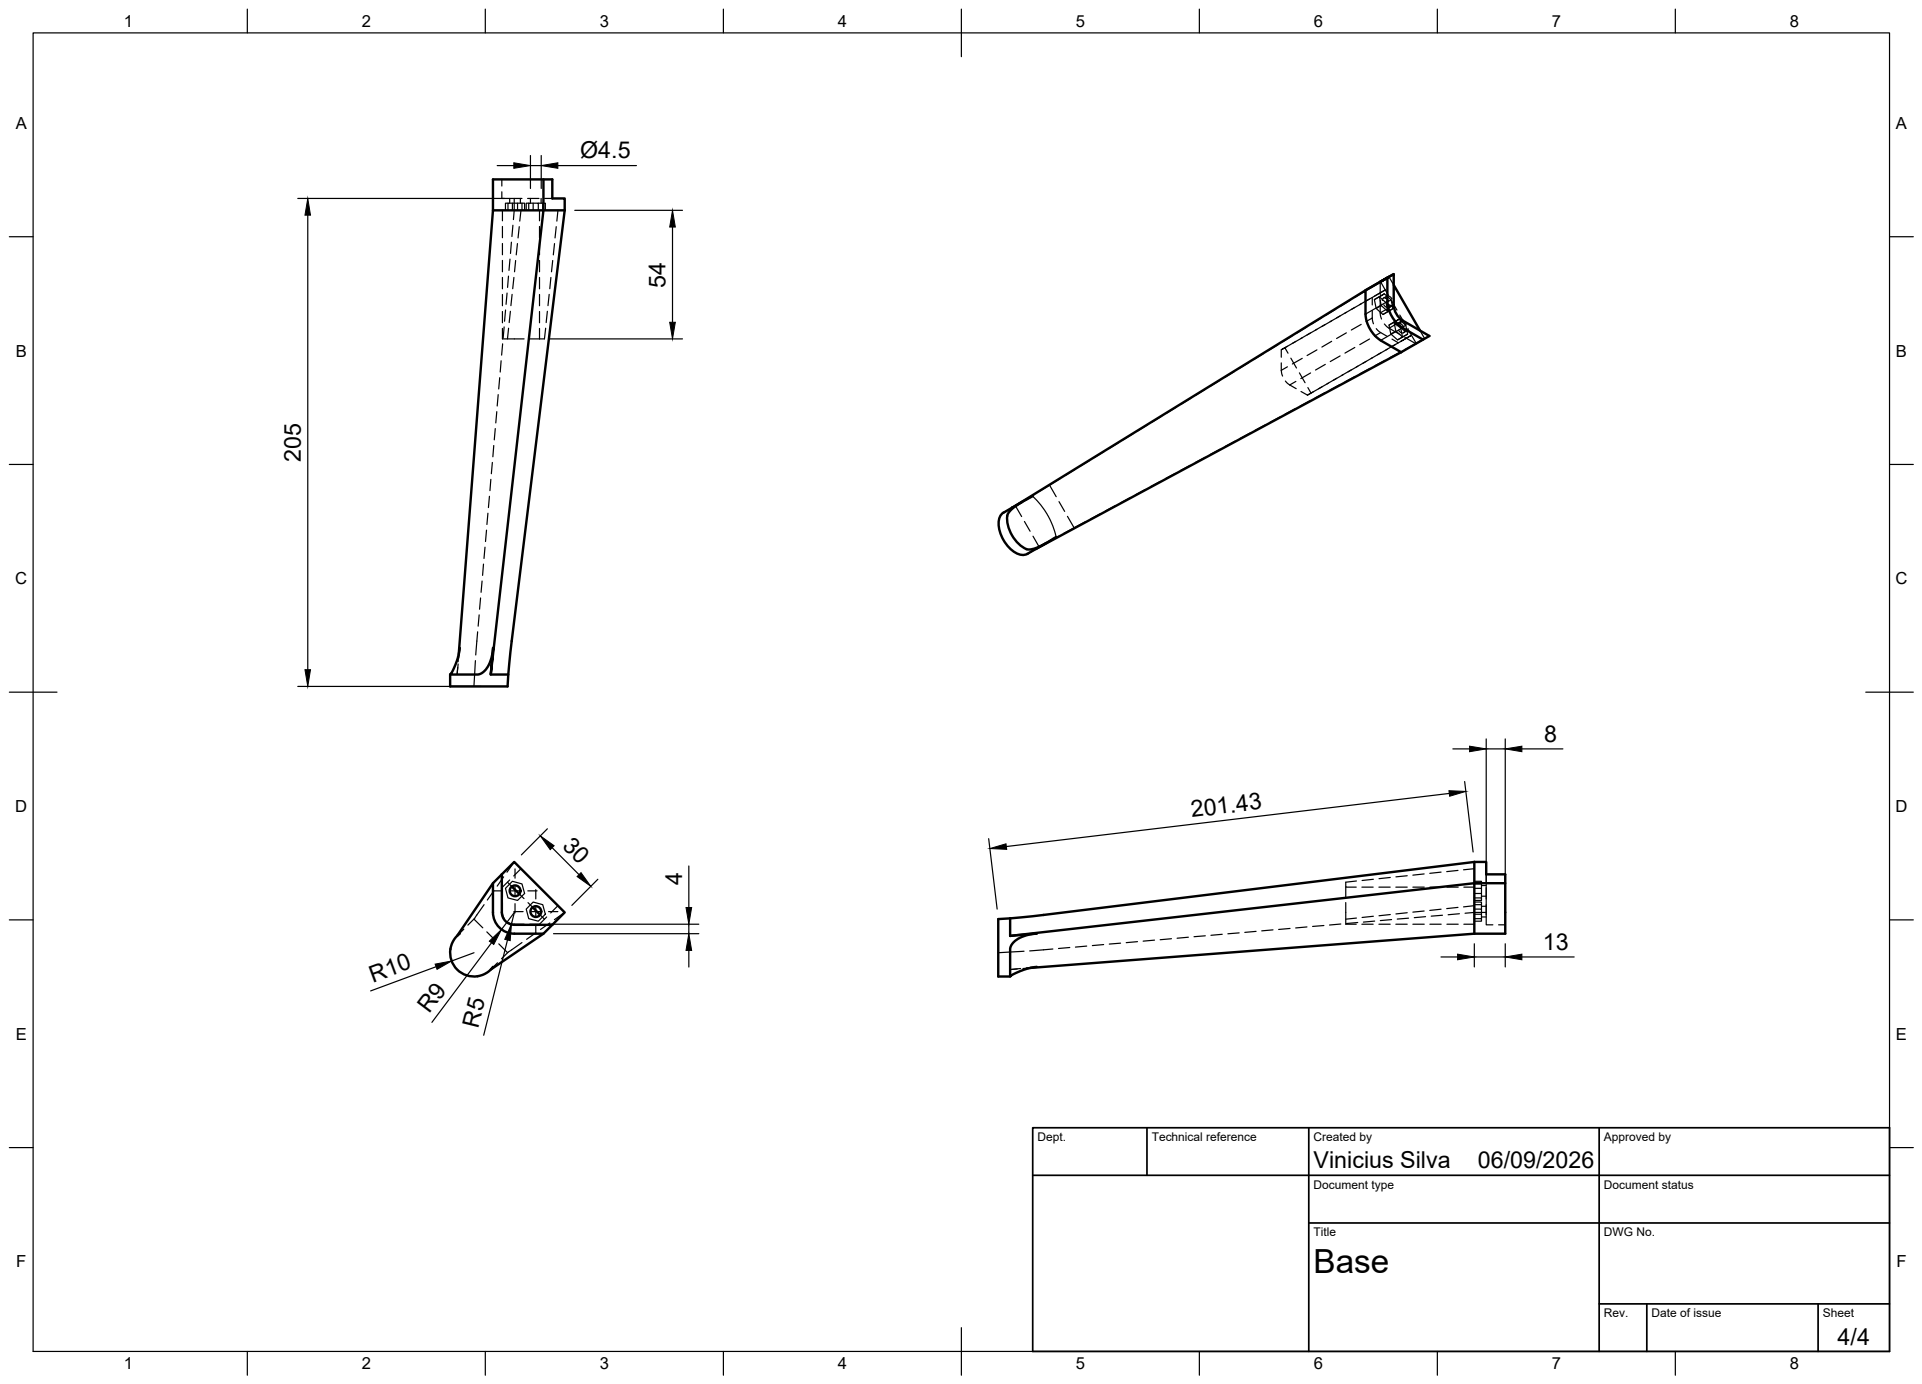
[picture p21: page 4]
Title; DWG No.

Dept. | Technical reference | Created by Vinicius Silva 06/09/2026 | Approved by

Document type | Document status

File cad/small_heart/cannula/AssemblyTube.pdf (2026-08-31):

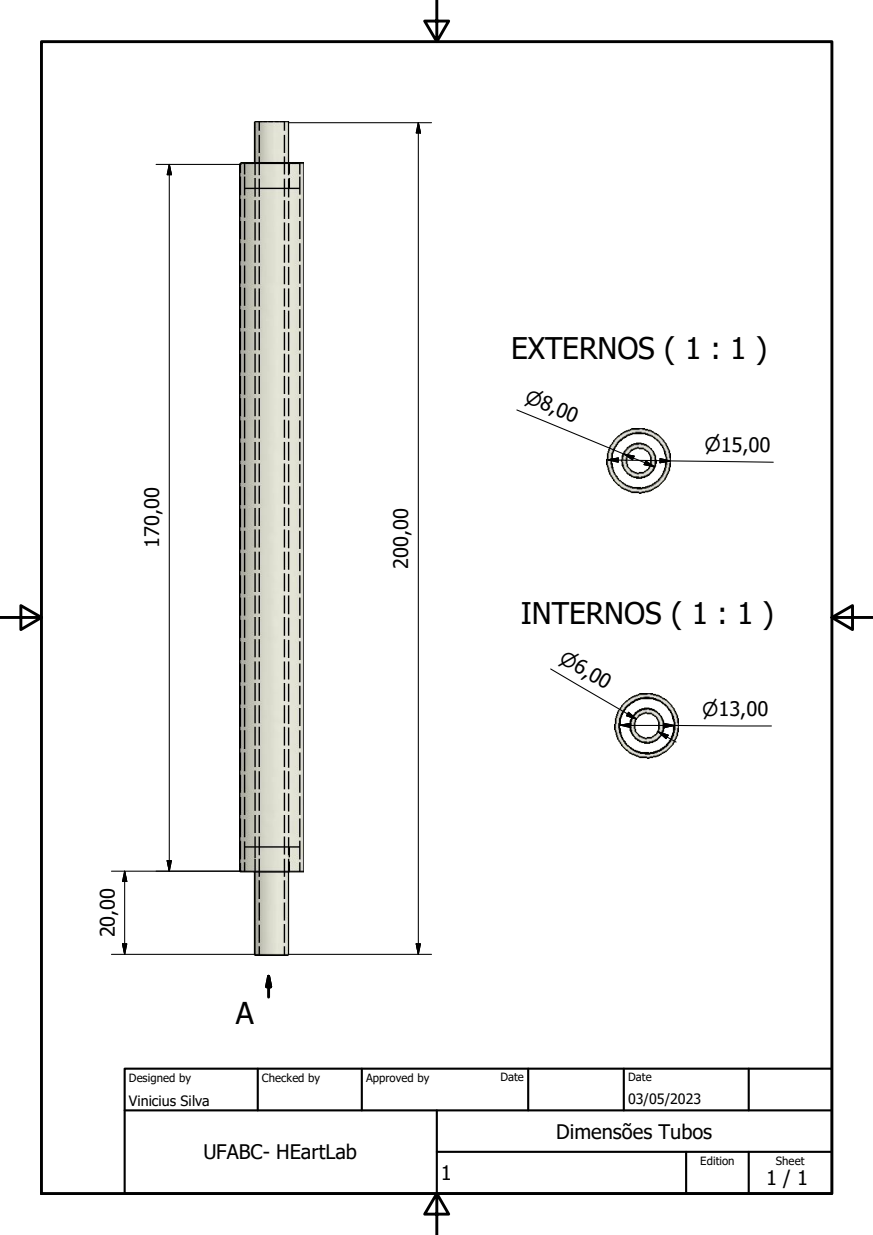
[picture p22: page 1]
EXTERNOS ( 1 : 1 ); INTERNOS ( 1 : 1 ); UFABC- HEartLab; Vinicius Silva; Designed by; Checked by; Approved by; Date; Edition; Sheet

Dimens}es Tubos

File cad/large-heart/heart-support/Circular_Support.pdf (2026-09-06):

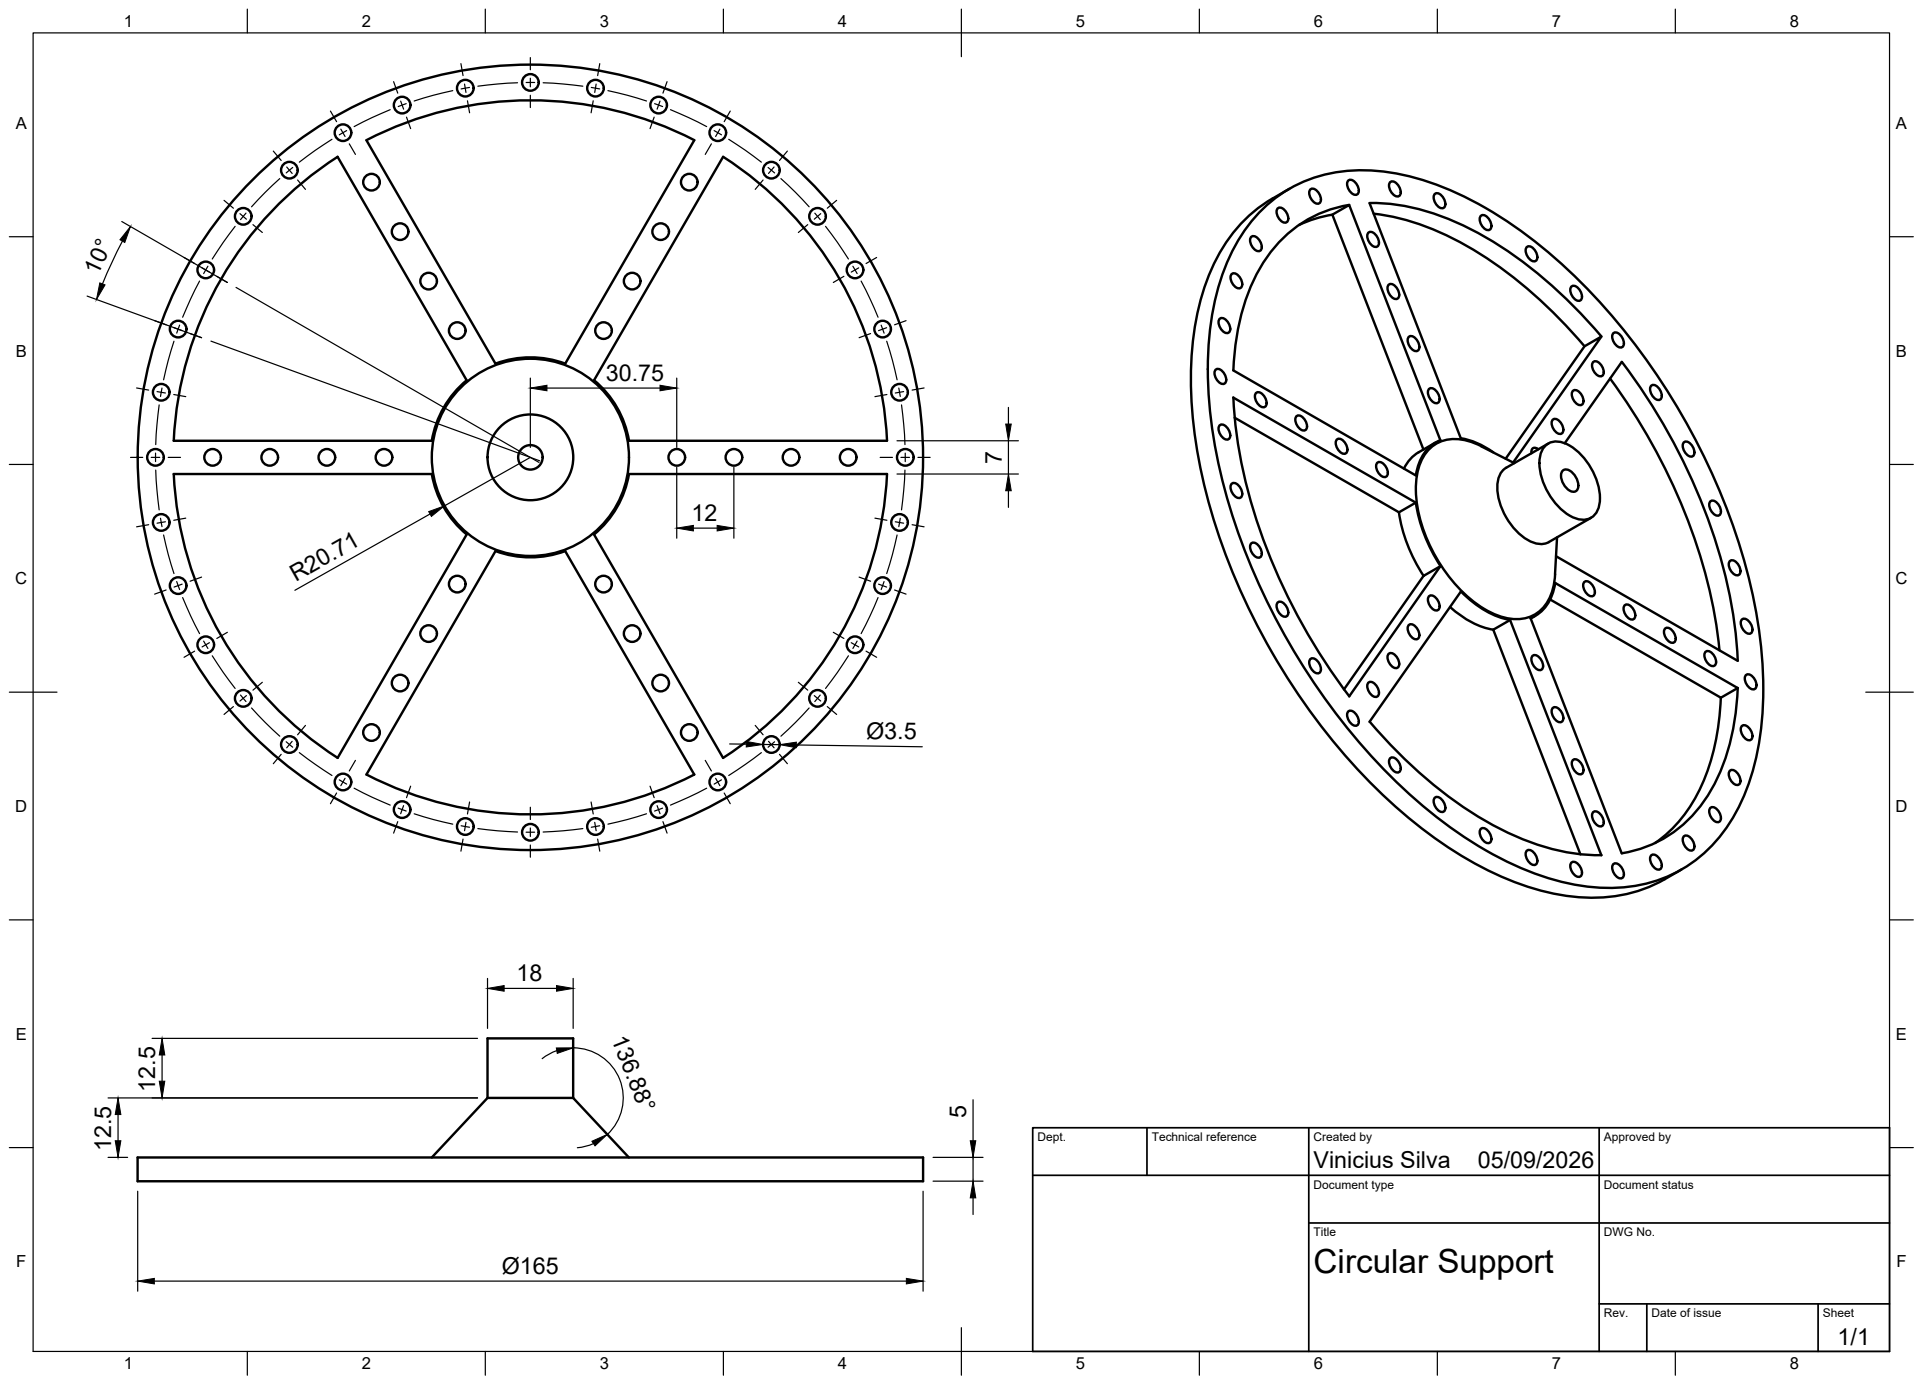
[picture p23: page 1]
Title; DWG No.; Rev.; Date of issue; Sheet; Circular Support

Dept. | Technical reference | Created by Vinicius Silva 05/09/2026 | Approved by

Document type | Document status

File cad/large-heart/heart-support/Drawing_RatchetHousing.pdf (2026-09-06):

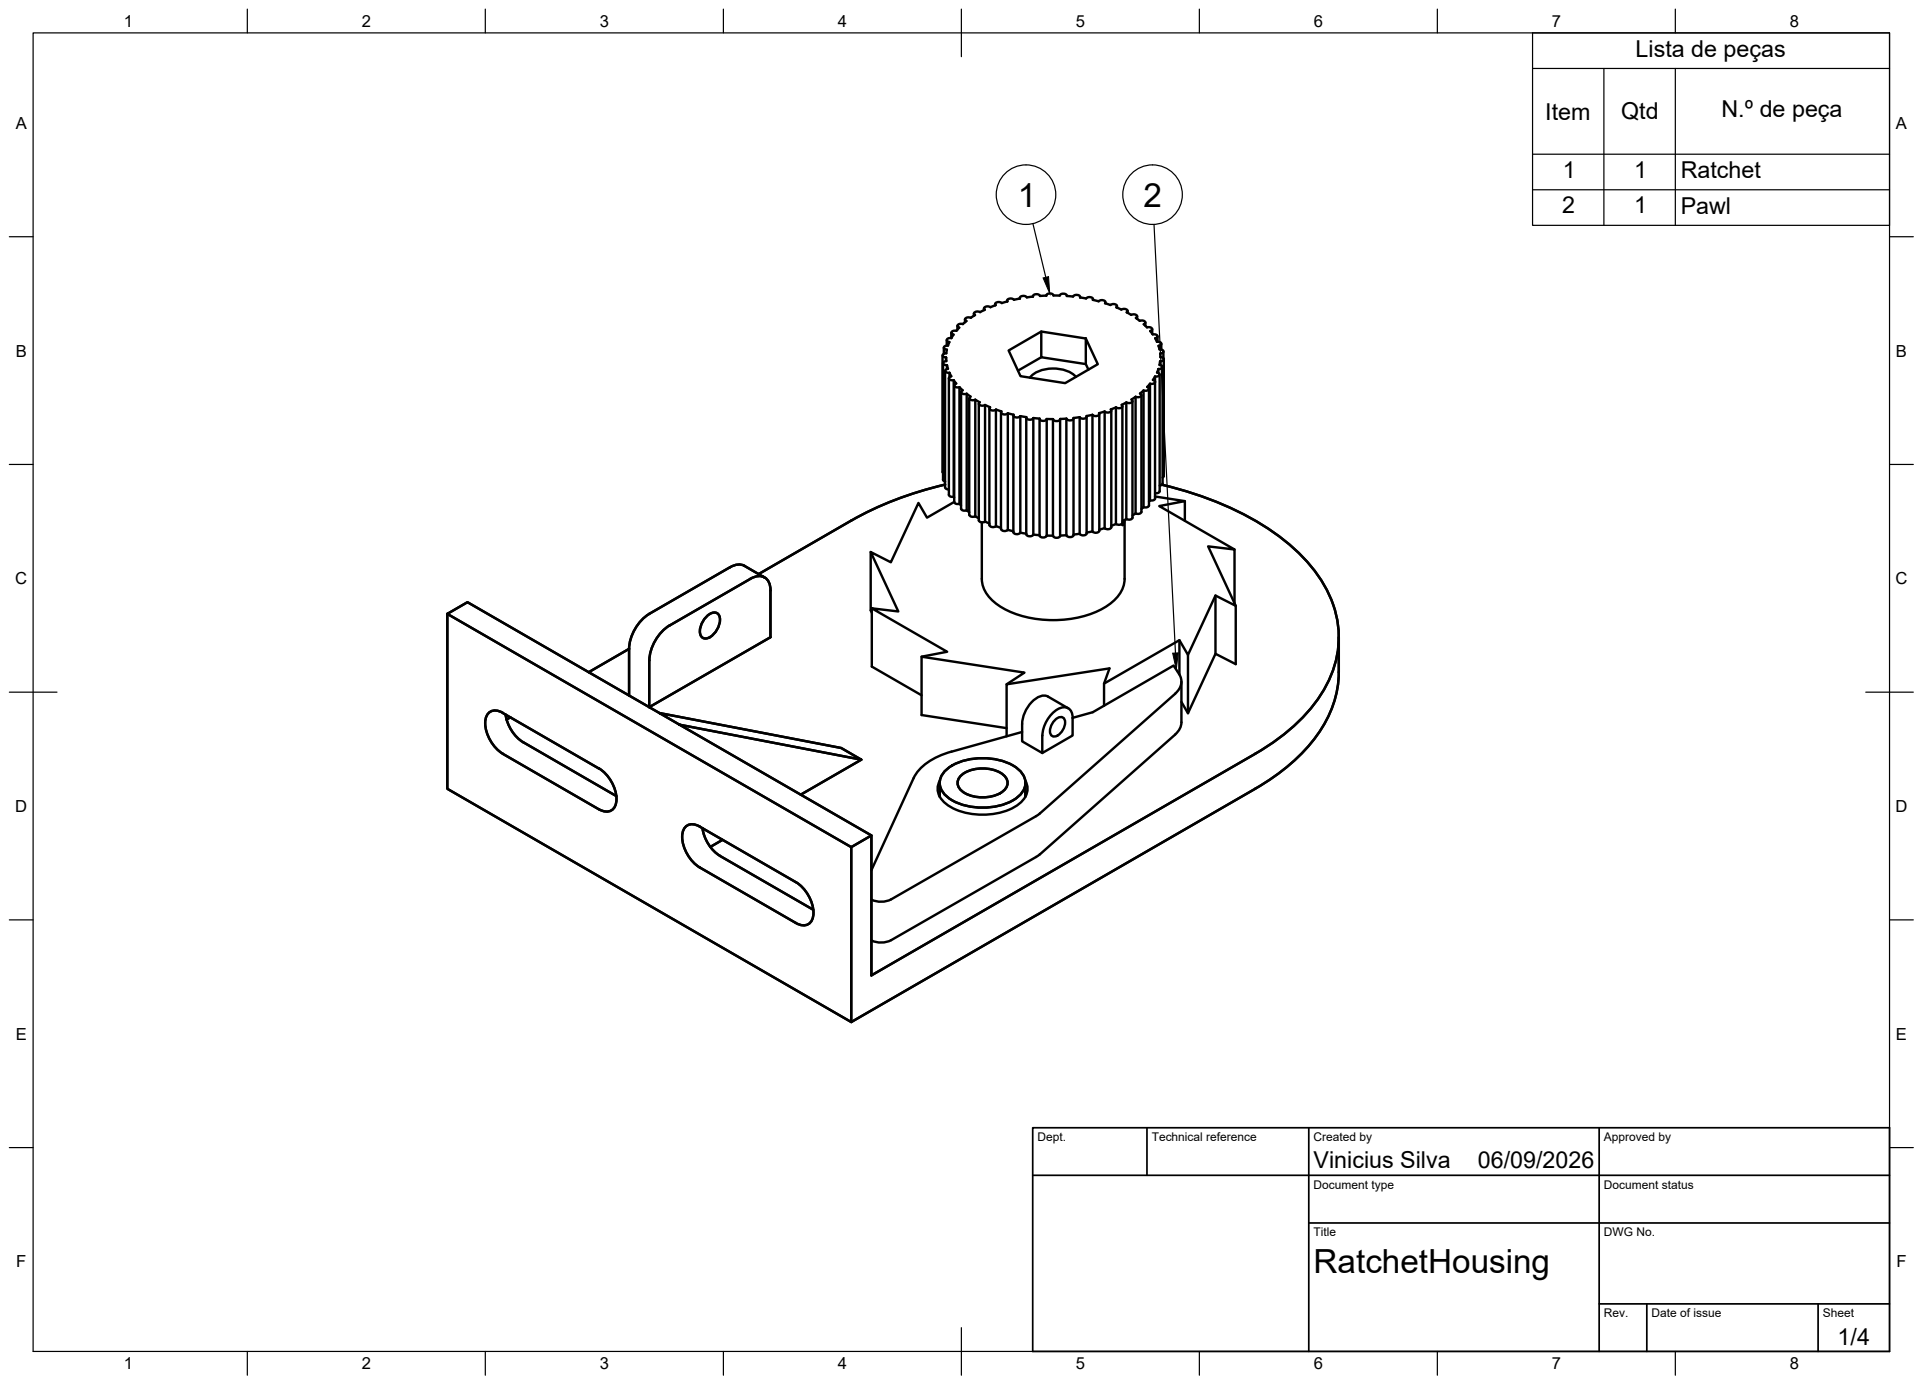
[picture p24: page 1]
Title; DWG No.; Rev.; Date of issue; Sheet

Lista de peças

Item | Qtd | N.º de peça

1 | 1 | Ratchet

Dept. | Technical reference | Created by Vinicius Silva 06/09/2026 | Approved by

Document type | Document status

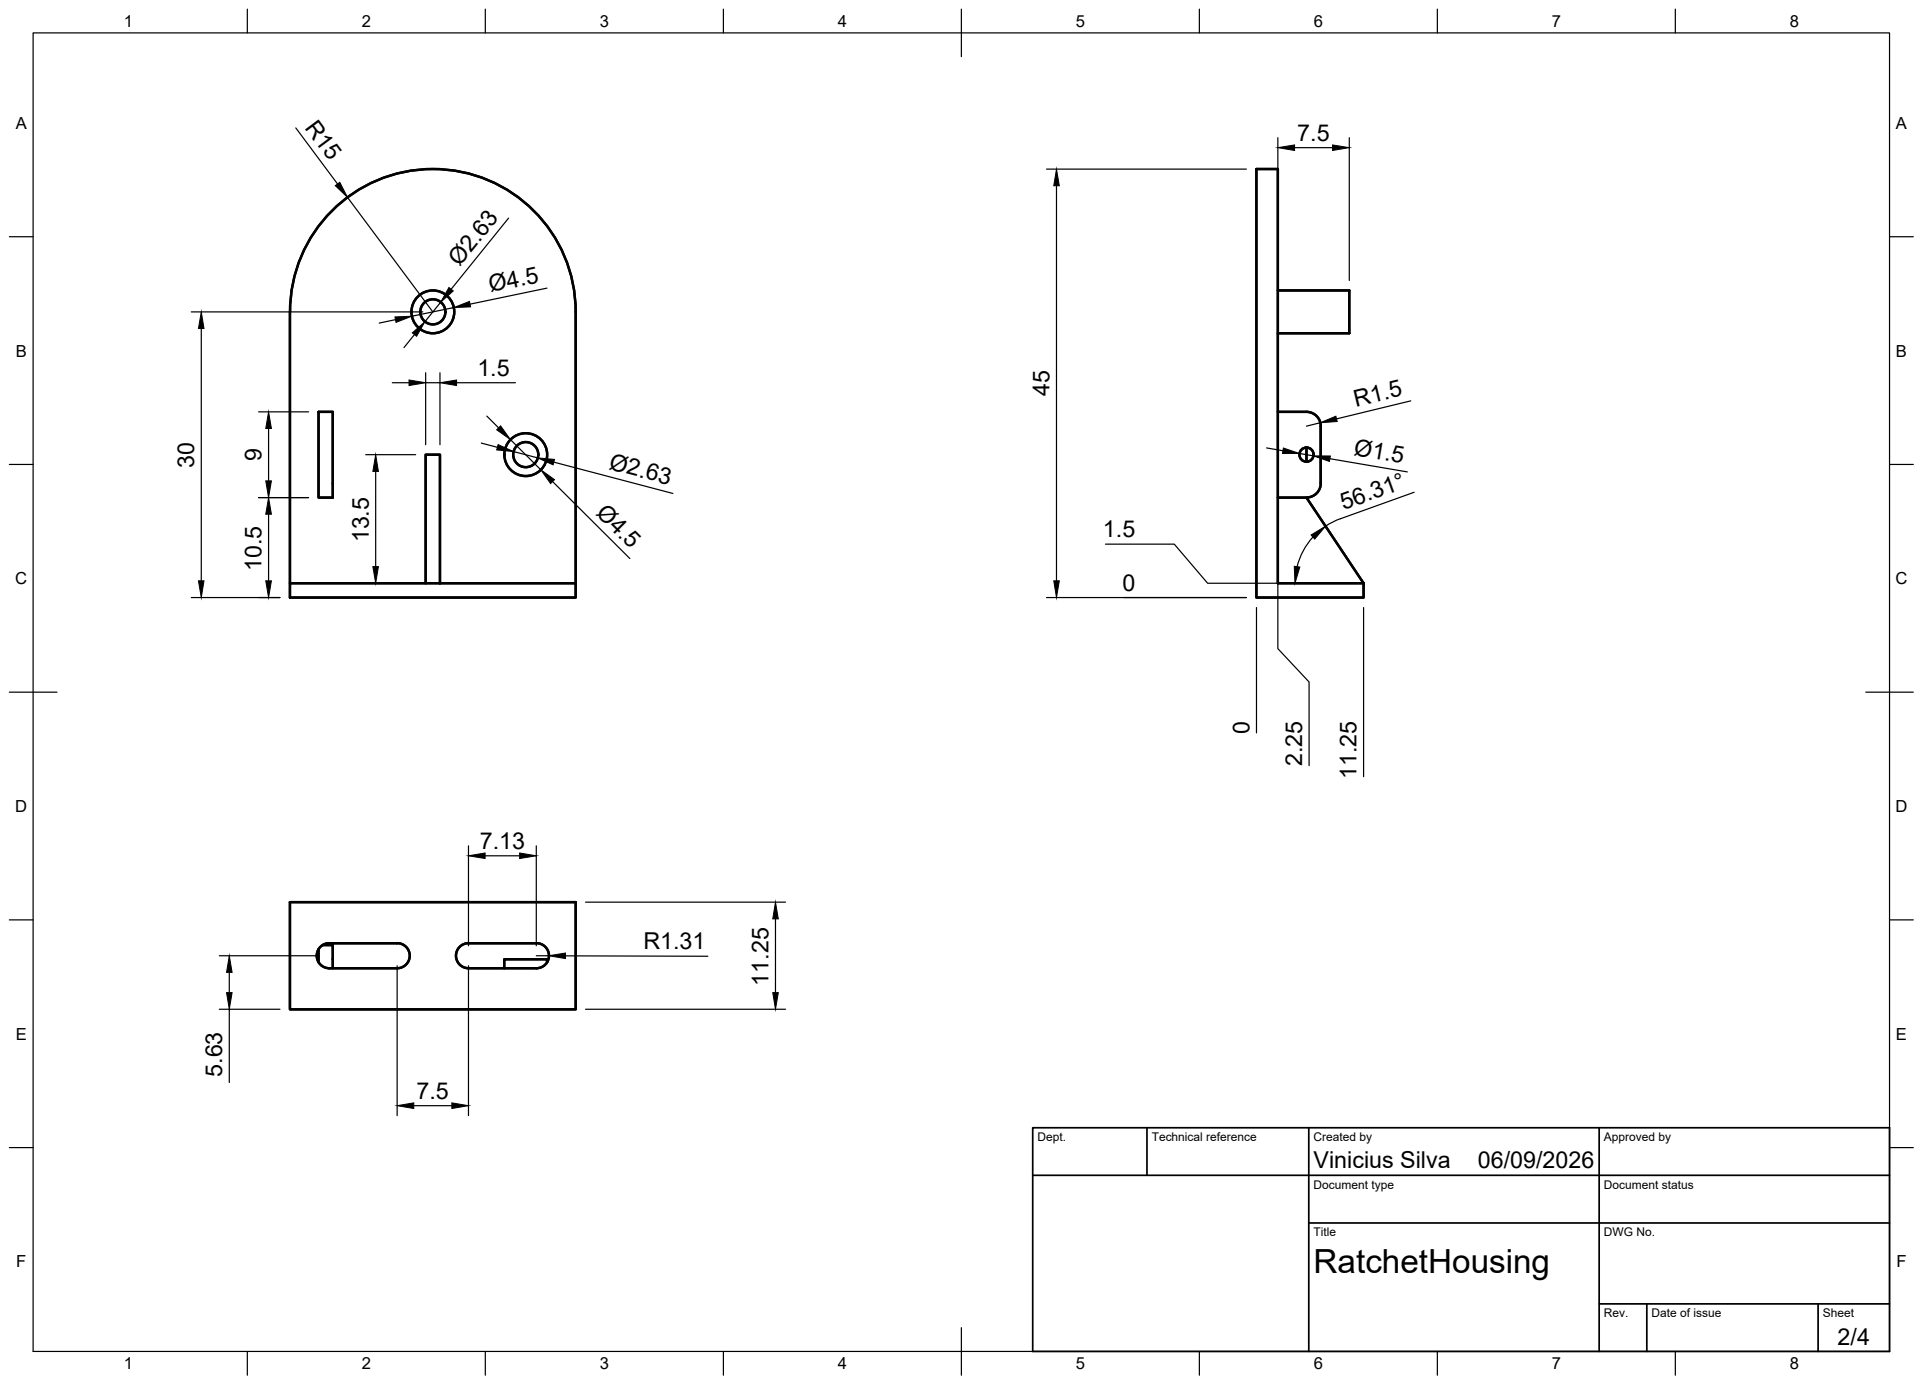
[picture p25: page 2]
Title; DWG No.

Dept. | Technical reference | Created by Vinicius Silva 06/09/2026 | Approved by

Document type | Document status

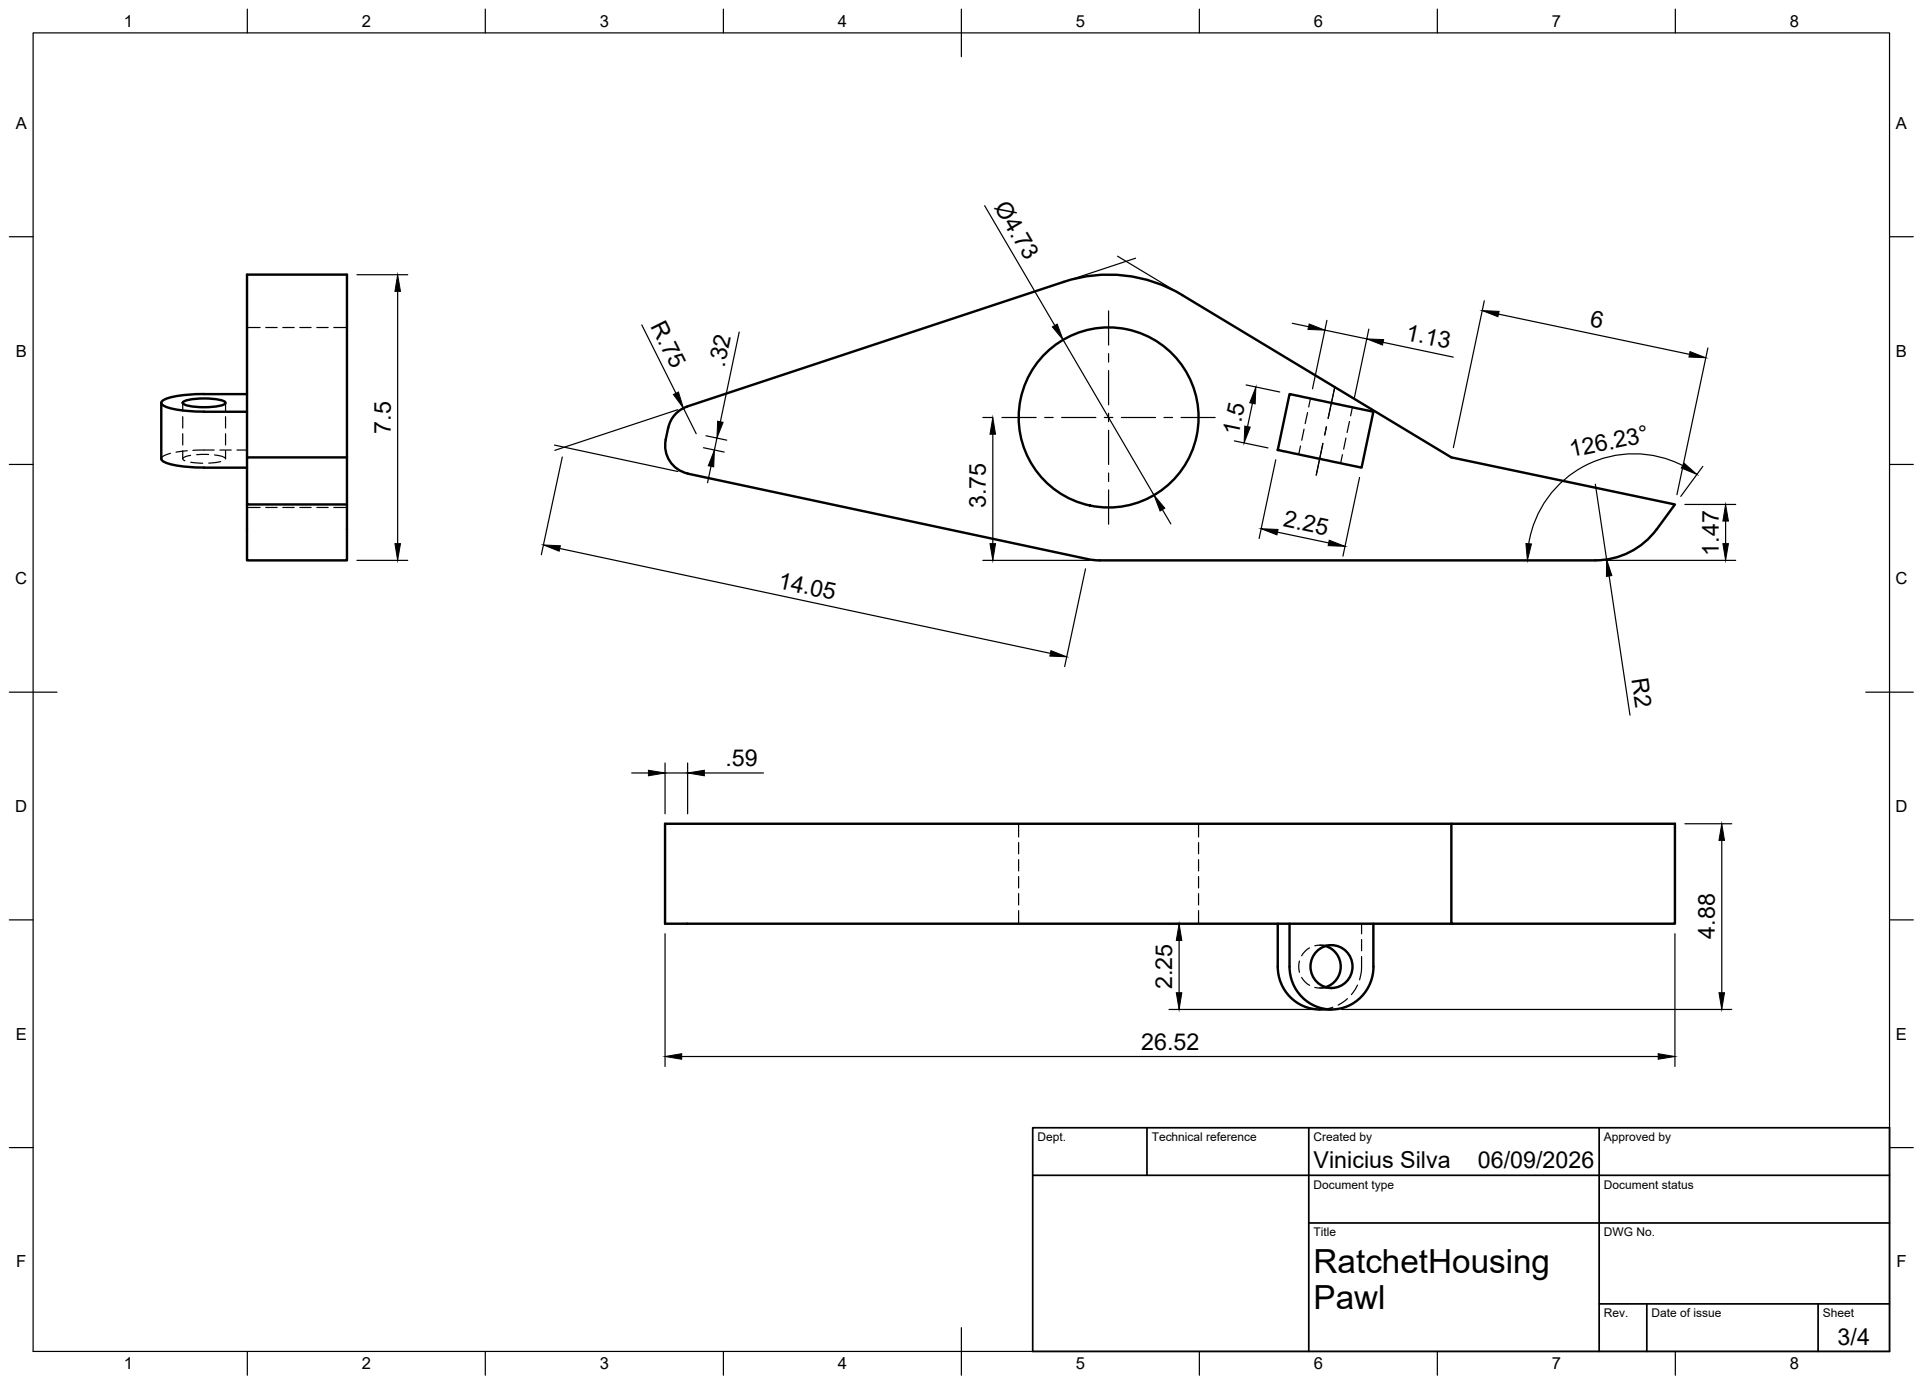
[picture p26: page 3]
Title; DWG No.

Dept. | Technical reference | Created by Vinicius Silva 06/09/2026 | Approved by

Document type | Document status

Title; DWG No.

Dept. | Technical reference | Created by Vinicius Silva 06/09/2026 | Approved by

Document type | Document status

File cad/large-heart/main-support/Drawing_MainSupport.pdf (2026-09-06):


Dept. | Technical reference | Created by Vinicius Silva 06/09/2026 | Approved by

Document type | Document status

Title MainHeartSupport_400_Connector_v3 | DWG No.

Rev. | Date of issue | Sheet 1/1

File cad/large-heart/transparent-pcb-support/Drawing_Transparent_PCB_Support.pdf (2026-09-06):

Title; DWG No.; Rev.; Date of issue; Sheet

Dept. | Technical reference | Created by Vinicius Silva 05/08/2026 | Approved by

Document type | Document status

Top Internal Support

Title; DWG No.

Dept. | Technical reference | Created by Vinicius Silva 05/08/2026 | Approved by

Document type | Document status

Top External Support

Title; DWG No.; Vinicius Silva 190.35

Dept. | Technical reference | Created by 05/08/2026 | Approved by

Document type | Document status

Bottom Internal Support

Title; DWG No.; Connection support; Scale 2:1; Scale 1:2

Dept. | Technical reference | Created by Vinicius Silva 05/08/2026 | Approved by

Document type | Document status

NOTE: Print 6 copies

Title; DWG No.; Connection support

Dept. | Technical reference | Created by Vinicius Silva 05/08/2026 | Approved by

Document type | Document status

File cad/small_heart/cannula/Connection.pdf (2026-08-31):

Connection; Vinicius Silva; Scale 5:1; Designed by; Checked by; Approved by; Date; Edition; Sheet

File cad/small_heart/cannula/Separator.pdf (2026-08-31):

P22,00

Scale 2:1; Separator; Vinicius Silva; Designed by; Checked by; Approved by; Date; Edition; Sheet

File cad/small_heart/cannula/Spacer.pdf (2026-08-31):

Vinicius Silva; Designed by; Checked by; Approved by; Date; Edition; Sheet

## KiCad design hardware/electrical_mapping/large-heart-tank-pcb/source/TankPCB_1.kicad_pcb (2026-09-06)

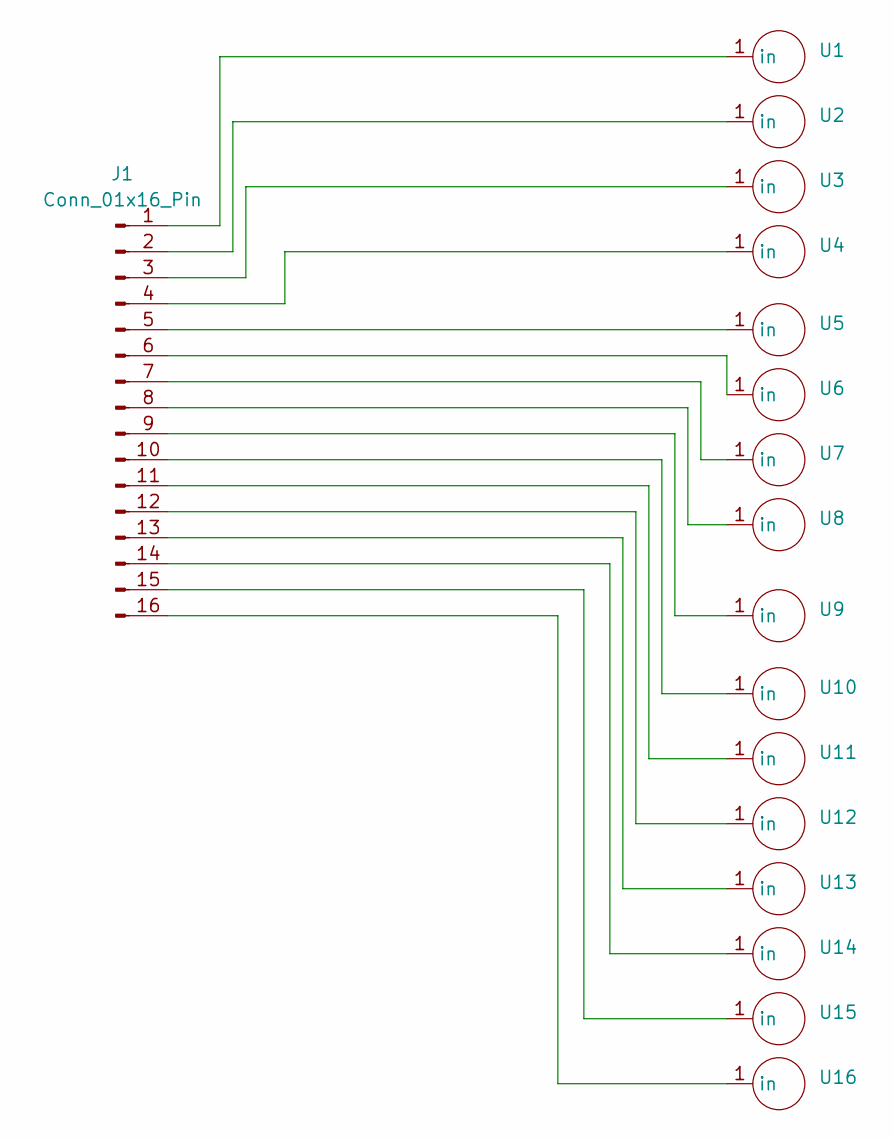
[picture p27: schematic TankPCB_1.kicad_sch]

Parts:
J1: Conn_01x16_Pin; PinHeader_1x16_P2.54mm_Horizontal
U1, U2, U3, U4, U5, U6, U7, U8, U9, U10, U11, U12, U13, U14, U15, U16: Round_Pad

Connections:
unnamed: J1.1, U1.1 (in)
unnamed: J1.2, U2.1 (in)
unnamed: J1.3, U3.1 (in)
unnamed: J1.4, U4.1 (in)
unnamed: J1.5, U5.1 (in)
unnamed: J1.6, U6.1 (in)
unnamed: J1.7, U7.1 (in)
unnamed: J1.8, U8.1 (in)
unnamed: J1.9, U9.1 (in)
unnamed: J1.10, U10.1 (in)
unnamed: J1.11, U11.1 (in)
unnamed: J1.12, U12.1 (in)
unnamed: J1.13, U13.1 (in)
unnamed: J1.14, U14.1 (in)
unnamed: J1.15, U15.1 (in)
unnamed: J1.16, U16.1

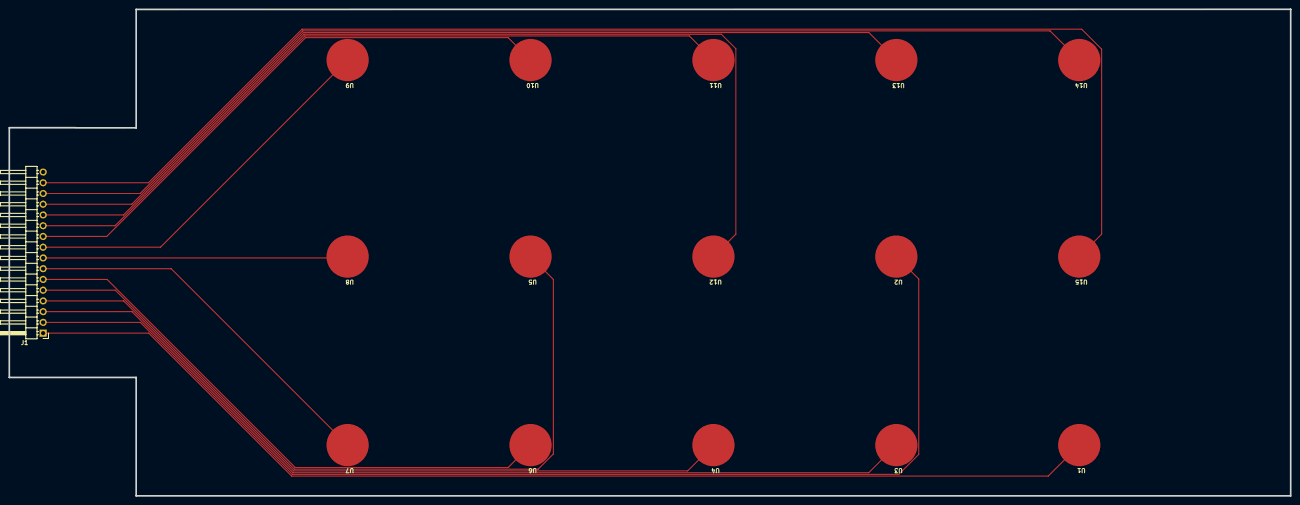
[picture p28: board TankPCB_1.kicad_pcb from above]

Board: 2 copper layers, 303.0 x 115.0 mm, 16 parts (0 on the bottom side), 15 nets.

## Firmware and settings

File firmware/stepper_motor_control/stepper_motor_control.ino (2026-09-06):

#include <AccelStepper.h>

// Define stepper motor connections and motor interface type.
#define motorInterfaceType 1
#define dirPin 5
#define stepPin 2

// Create a new instance of the AccelStepper class:
AccelStepper stepper = AccelStepper(motorInterfaceType, stepPin, dirPin);

const int microStep = 16;
const float stepsPerRevolution = microStep*200;
const float stepsPerDegree = stepsPerRevolution/360;
int incomingInt = 0;  // initiation variable
float incomingAngle = 0; // Angle to move to

int stepCount = 0;         // number of steps the motor will take
int moveFor = 0;

void setup() {
  // initialize the serial port:
  Serial.begin(57600);
  pinMode(stepPin,OUTPUT);
  pinMode(dirPin,OUTPUT);

  stepper.setMaxSpeed(400); // Maximun speed of the motor
  stepper.setAcceleration(100); // Acceleration of the motor
}

void loop() {
  if (Serial.available() > 1) {    
    incomingInt = recvData();
    Serial.print("incomingInt: ");
    Serial.println(incomingInt);
    
    incomingAngle = recvData();
    Serial.print("incomingAngle: ");
    Serial.println(incomingAngle);    

    // Move to: Angle
    moveFor = stepsPerDegree*incomingAngle;
    stepCount = stepCount + moveFor;
    
    stepper.moveTo(stepCount);   
    stepper.runToPosition();
      
    // say how many steps you run:
    Serial.print("Step Count: ");
    Serial.println(stepCount);
    Serial.flush();
    }
  }


// Receive data from Serial
float recvData(){
  digitalWrite(13,LOW);
  delay(1);
  digitalWrite(13,HIGH);
  float incomingData = Serial.parseFloat();
 
  return incomingData;
}

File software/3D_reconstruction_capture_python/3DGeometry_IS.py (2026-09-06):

import cv2
import serial
import time
import tkinter as tk
from tkinter import ttk, filedialog, messagebox
from serial.tools import list_ports
import os
import sys
import threading

# Configuration shared with the HEartLab stepper-motor firmware.
SERIAL_BAUD_RATE = 57600
SERIAL_TIMEOUT_S = 0.25
MOTOR_COMPLETION_TIMEOUT_S = 30.0
DEFAULT_NUM_IMAGES = 100
DEFAULT_SETTLING_DELAY_S = 3.0
MAX_CAMERAS = 10


def open_camera(camera_index):
    """Open a camera, preferring DirectShow on Windows."""
    if sys.platform.startswith("win"):
        cap = cv2.VideoCapture(camera_index, cv2.CAP_DSHOW)
        if cap.isOpened():
            return cap
        cap.release()

    return cv2.VideoCapture(camera_index)


def list_cameras(max_cameras=MAX_CAMERAS):
    """Return indices for cameras that OpenCV can open."""
    cameras = []
    for i in range(max_cameras):
        cap = open_camera(i)
        if cap.isOpened():
            cameras.append(i)
        cap.release()
    return cameras


def list_serial_ports():
    """Return available serial/COM port names."""
    return [port.device for port in list_ports.comports()]


def set_camera_exposure(camera, exposure_value):
    """Set OpenCV exposure. Exact behavior is camera/backend dependent."""
    if not camera.set(cv2.CAP_PROP_EXPOSURE, float(exposure_value)):
        print("Warning: camera/backend did not confirm the exposure setting.")


def set_camera_gain(camera, gain_value):
    """Set OpenCV gain. Exact behavior is camera/backend dependent."""
    if not camera.set(cv2.CAP_PROP_GAIN, float(gain_value)):
        print("Warning: camera/backend did not confirm the gain setting.")


def capture_and_save_image(camera, image_num, save_folder):
    """Capture one frame and save it as TIFF."""
    ret, frame = camera.read()
    if not ret or frame is None:
        raise RuntimeError(f"Failed to capture image {image_num}.")

    filename = os.path.join(save_folder, f"image_{image_num:03d}.tiff")
    if not cv2.imwrite(filename, frame):
        raise IOError(f"Failed to save image to {filename}")

    print(f"Saved {filename}")
    return frame


def wait_for_motor_completion(serial_port, timeout_s=MOTOR_COMPLETION_TIMEOUT_S):
    """
    Wait for the current Arduino firmware to report completion.

    The HEartLab stepper firmware prints a line beginning with
    "Step Count:" after runToPosition() finishes.
    """
    deadline = time.monotonic() + timeout_s
    received_lines = []

    while time.monotonic() < deadline:
        raw = serial_port.readline()
        if not raw:
            continue

        line = raw.decode(errors="replace").strip()
        if line:
            received_lines.append(line)
            print(f"Arduino: {line}")

        if line.startswith("Step Count:"):
            return line

    details = " | ".join(received_lines[-5:])
    raise TimeoutError(
        "Timed out waiting for the stepper controller to finish moving."
        + (f" Last messages: {details}" if details else "")
    )


def send_serial_command(serial_port, angle, reverse=False):
    """Command one relative angular movement and wait until it is complete."""
    if reverse:
        angle = -angle

    # The current Arduino firmware expects two numeric values:
    # an initiation value followed by the requested angle.
    command = f"1\n{angle:.4f}\n"

    # Remove any stale startup/debug text before a new command.
    serial_port.reset_input_buffer()
    serial_port.write(command.encode("ascii"))
    serial_port.flush()

    print(f"Sent angle command: {angle:.4f}°")
    return wait_for_motor_completion(serial_port)


def live_feed_for_adjustments(camera):
    """
    Show a live feed for exposure/gain adjustment.

    Exposure and gain ranges are implementation dependent and must be
    verified for the connected Imaging Source camera and OpenCV backend.
    """
    print("Press 'r' when ready to close the adjustment window and continue.")
    cv2.namedWindow("Camera Feed")

    def update_exposure(val):
        # Representative OpenCV/DirectShow mapping used by the original code.
        exposure_value = val / 10.0 - 10.0
        set_camera_exposure(camera, exposure_value)

    def update_gain(val):
        gain_value = float(val)
        set_camera_gain(camera, gain_value)

    cv2.createTrackbar("Exposure", "Camera Feed", 50, 100, update_exposure)
    cv2.createTrackbar("Gain", "Camera Feed", 50, 100, update_gain)

    while True:
        ret, frame = camera.read()
        if not ret or frame is None:
            raise RuntimeError("Failed to read from camera during live preview.")

        cv2.putText(
            frame,
            "Press 'r' when ready",
            (10, 30),
            cv2.FONT_HERSHEY_SIMPLEX,
            1,
            (0, 0, 255),
            2,
        )
        cv2.imshow("Camera Feed", frame)

        if cv2.waitKey(1) & 0xFF == ord("r"):
            break

        if cv2.getWindowProperty("Camera Feed", cv2.WND_PROP_VISIBLE) < 1:
            break

    cv2.destroyWindow("Camera Feed")


def show_live_feed(camera_index):
    """Show a preview of the selected camera until q or window close."""
    cap = open_camera(camera_index)
    if not cap.isOpened():
        print(f"Failed to open camera {camera_index}")
        return

    try:
        cv2.namedWindow("Live Camera Feed")
        while True:
            ret, frame = cap.read()
            if not ret or frame is None:
                print("Failed to read from camera.")
                break

            cv2.imshow("Live Camera Feed", frame)

            if cv2.getWindowProperty("Live Camera Feed", cv2.WND_PROP_VISIBLE) < 1:
                break

            if cv2.waitKey(1) & 0xFF == ord("q"):
                break
    finally:
        cap.release()
        cv2.destroyWindow("Live Camera Feed")
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

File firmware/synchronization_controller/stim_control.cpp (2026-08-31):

#include "stim_control.h"
#include <Arduino.h>

// Use Teensy IntervalTimer
#include <IntervalTimer.h>

// -----------------------
// Pin Definitions
// -----------------------
#define STIM_PIN 21  // Adjust for your wiring on Teensy

// -----------------------
// Modes and State
// -----------------------
enum STIMMode { CONTINUOUS, BURST, IDLE };
volatile STIMMode stimMode = CONTINUOUS;

// -----------------------
// Type Parameters
// -----------------------
struct STIMType {
    uint32_t pulseWidth;  // In microseconds
    uint32_t period;      // In microseconds
    uint8_t pulseCount;   // Number of pulses
    bool enabled;         // Enabled/Disabled
};

// Example default configuration (adjust as needed)
STIMType stimTypes[5] = {
    {2000, 1000000, 1, true},   // S0
    {2000, 1000000, 8, false},  // S1
    {2000, 1000000, 8, false},  // S2
    {2000, 1000000, 8, false},  // S3
    {2000, 1000000, 8, false}   // S4
};

// -----------------------
// Internal State
// -----------------------
volatile uint8_t currentType = 0;
volatile uint8_t currentPulse = 0;
volatile bool stimRunning = false;
volatile bool startBurstPending = false; // Flag to switch from CONTINUOUS to BURST

// -----------------------
// Teensy IntervalTimers
// -----------------------
IntervalTimer continuousTimer;
IntervalTimer burstTimer;
// -----------------------
// Forward Declarations
// -----------------------
void onSTIMContinuous();
void onSTIMBurst();

// -----------------------
// Setup
// -----------------------
void setupSTIM() {
    pinMode(STIM_PIN, OUTPUT);
    digitalWrite(STIM_PIN, LOW);
}

// -----------------------
// Continuous Mode Callback
// -----------------------
void onSTIMContinuous() {
    // Stop repeating so we can manually restart (mimics "one-shot")
    continuousTimer.end();

    static bool state = false;
    state = !state; // Toggle HIGH/LOW each time

    if (state) {
        digitalWrite(STIM_PIN, HIGH);
        // Serial.printf("PULSE_%d_%02d\n", 0, stimTypes[0].pulseWidth / 1000);

        // Schedule turning the pin LOW after pulseWidth microseconds
        continuousTimer.begin(onSTIMContinuous, stimTypes[0].pulseWidth);
    } else {
        digitalWrite(STIM_PIN, LOW);

        if (startBurstPending) {
            // We’ve just finished a pulse in continuous mode
            // Now switch to burst mode
            startBurstPending = false;
            stimMode = BURST;
            currentType = 0;   // Start with S0
            currentPulse = 1;  // We already did one pulse for S0?

            // Instead of continuing continuous mode, use the burstTimer to handle next step
            burstTimer.begin(onSTIMBurst, stimTypes[0].period - stimTypes[0].pulseWidth);
        } else {
            // Remain in continuous mode
            // Wait for the remainder of the period before the next pulse
            continuousTimer.begin(onSTIMContinuous, stimTypes[0].period - stimTypes[0].pulseWidth);
        }
    }
}

// -----------------------
// Burst Mode Callback
// -----------------------
void onSTIMBurst() {
    // Stop repeating
    burstTimer.end();

    if (!stimRunning) {
        digitalWrite(STIM_PIN, LOW);
        return;
    }

    static bool state = false;
    state = !state;

    if (state) {
        digitalWrite(STIM_PIN, HIGH);
        // Serial.printf("PULSE_%d_%02d\n", currentType, stimTypes[currentType].pulseWidth / 1000);

        // Schedule pin LOW after pulseWidth microseconds
        burstTimer.begin(onSTIMBurst, stimTypes[currentType].pulseWidth);
    } else {
        digitalWrite(STIM_PIN, LOW);

        currentPulse++;
        // Check if we’ve done enough pulses for this STIM type
        if (currentPulse >= stimTypes[currentType].pulseCount) {
            currentPulse = 0;
            currentType++;
            // Skip disabled types
            while (currentType < 5 && !stimTypes[currentType].enabled) {
                currentType++;
            }

            if (currentType >= 5) {
                // Completed all enabled bursts
                stimRunning = false;
                Serial.println("(Teensy) Burst mode completed.");
                Serial1.println("(Teensy) Burst mode completed.");
                digitalWrite(STIM_PIN, LOW);
                return;
            }
        }

        // Schedule next pulse (HIGH) after the rest of the period
        burstTimer.begin(onSTIMBurst, stimTypes[currentType].period - stimTypes[currentType].pulseWidth);
    }
}


// -----------------------
// Public Control Functions
// -----------------------
void startSTIMContinuous() {
    stimMode = CONTINUOUS;
    stimRunning = true;

    // Immediately schedule the first “LOW → HIGH” event after a full period
    continuousTimer.begin(onSTIMContinuous, stimTypes[0].period);
}

void stopSTIMContinuous() {
    stimRunning = false;
    digitalWrite(STIM_PIN, LOW);
    continuousTimer.end();
}

void startSTIMBurst() {
    if (stimMode == CONTINUOUS && stimRunning) {
        // We’re mid-continuous-pulse; wait for the current S0 cycle to finish
        startBurstPending = true;
        return;
    }
    // Otherwise, start the burst sequence
    stimMode = BURST;
    stimRunning = true;
    currentType = 1;  // Start at S1, skipping S0
    currentPulse = 0;

    // Schedule the first pulse for the new type
    burstTimer.begin(onSTIMBurst, stimTypes[currentType].period);
}

void stopSTIMBurst() {
    stimRunning = false;
    digitalWrite(STIM_PIN, LOW);
    burstTimer.end();
}

// -----------------------
// Update Parameters
// -----------------------
void setSTIMTypeParams(uint8_t type, uint32_t pulseWidthMs, uint32_t periodMs, uint8_t pulseCount, bool enabled) {
    if (type < 1 || type > 5) {
        Serial.printf("Invalid STIM type: %d\n", type);
        return;
    }
    type--; // Convert from 1-based to 0-based indexing

    stimTypes[type].pulseWidth = pulseWidthMs * 1000; // ms → µs
    stimTypes[type].period     = periodMs  * 1000;    // ms → µs
    stimTypes[type].pulseCount = pulseCount;
    stimTypes[type].enabled    = enabled;

    // Apply built-in offset
    stimTypes[type].pulseWidth -= 2;
    stimTypes[type].period     -= 10;

    // For debugging
    // Serial.printf("Type %d: PulseWidth=%dus, Period=%dus, PulseCount=%d, Enabled=%s\n",
    //               type, stimTypes[type].pulseWidth, stimTypes[type].period,
    //               stimTypes[type].pulseCount, enabled ? "ON" : "OFF");
}

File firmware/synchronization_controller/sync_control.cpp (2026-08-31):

#include "sync_control.h"
#include <IntervalTimer.h>

// ------------------------------------------------------------------------
// PIN DEFINITIONS (Update for Teensy 4.1!)
// ------------------------------------------------------------------------
const int SIGNAL_PINS[] = {6, 7, 8};  // Three SYNC signals
const int REC_PIN       = 9;         // REC signal
static const int NUM_SIGNALS = sizeof(SIGNAL_PINS) / sizeof(SIGNAL_PINS[0]);

// ------------------------------------------------------------------------
// TIMER SETTINGS
// ------------------------------------------------------------------------
static const uint32_t TIMER_INTERVAL_US = 1;  // 10 microseconds => 100 kHz interrupt
volatile uint32_t master_counter = 0;          // increments each ISR cycle

// ------------------------------------------------------------------------
// SIGNAL PARAMETERS
// ------------------------------------------------------------------------
volatile uint32_t toggle_ticks[NUM_SIGNALS] = {2000, 2000, 2000}; // default 500Hz
volatile uint32_t high_ticks[NUM_SIGNALS]   = {1000, 1000, 1000}; // 50% duty
volatile uint32_t phase_ticks[NUM_SIGNALS]  = {0, 0, 0};
volatile bool     enabled[NUM_SIGNALS]      = {false, false, false};
volatile bool     high_state[NUM_SIGNALS]   = {false, false, false};

// ------------------------------------------------------------------------
// REC SIGNAL
// ------------------------------------------------------------------------
volatile bool rec_waiting             = false; 
volatile bool rec_active              = false;
volatile uint32_t rec_remaining_pulses= 0;
volatile bool prev_sync1_state        = false;
volatile bool rec_signal_complete     = false; // set true when REC finishes
// Keep track when a signal is freshly enabled
static volatile bool justEnabled[NUM_SIGNALS] = {false, false, false};

// ------------------------------------------------------------------------
// IntervalTimer for the SYNC loop
// ------------------------------------------------------------------------
IntervalTimer syncTimer;

// ------------------------------------------------------------------------
// onSyncTimer: Fires every 10µs
// ------------------------------------------------------------------------
static void onSyncTimer() {
    master_counter++;

   for (int i = 0; i < NUM_SIGNALS; i++) {
        if (enabled[i]) {

            // If we just enabled this signal, force the next cycle to start at 0
            if (justEnabled[i]) {
                // Force the local_counter to 0 by aligning master_counter
                // or just treat it like the first iteration
                // Option A: subtract (master_counter % toggle_ticks[i]) 
                //           so we appear to be "start of period"
                master_counter -= (master_counter % toggle_ticks[i]);
                
                // This ensures the next local_counter = 0
                justEnabled[i] = false;
            }

            // Now compute local_counter
            uint32_t local_counter = (master_counter + phase_ticks[i]) % toggle_ticks[i];
            bool shouldBeHigh = (local_counter < high_ticks[i]);

            // ... existing code ...
            if (shouldBeHigh && !high_state[i]) {
                high_state[i] = true;
                digitalWrite(SIGNAL_PINS[i], HIGH);
            } else if (!shouldBeHigh && high_state[i]) {
                high_state[i] = false;
                digitalWrite(SIGNAL_PINS[i], LOW);
            }
        }
    }

    // 2) Handle REC signal
    //    a) If waiting, start once SYNC1 is high
    if (rec_waiting) {
        // SYNC1 = index 0
        if (enabled[0] && high_state[0]) {
            rec_waiting = false;
            rec_active = true;
            digitalWrite(REC_PIN, HIGH);
        }
    }

    //    b) If active, decrement on each SYNC1 rising edge
    if (rec_active) {
        bool sync1_state = high_state[0];
        if (enabled[0] && !prev_sync1_state && sync1_state) {
            // Rising edge
            if (--rec_remaining_pulses == 0) {
                rec_active = false;
                digitalWrite(REC_PIN, LOW);
                rec_signal_complete = true;  // main loop can detect
            }
        }
        prev_sync1_state = sync1_state;
    }
}

// ------------------------------------------------------------------------
// Setup: Configure pins & start IntervalTimer
// ------------------------------------------------------------------------
void setup_sync_control() {
    for (int i = 0; i < NUM_SIGNALS; i++) {
        pinMode(SIGNAL_PINS[i], OUTPUT);
        digitalWrite(SIGNAL_PINS[i], LOW);
    }
    pinMode(REC_PIN, OUTPUT);
    digitalWrite(REC_PIN, LOW);

    // Start the hardware timer at 10µs intervals
    syncTimer.begin(onSyncTimer, (float)TIMER_INTERVAL_US);

    // (Optional) set a priority
    // syncTimer.priority(128);
}

// ------------------------------------------------------------------------
// set_signal_params: frequency (Hz), phase (degrees), duty_cycle (%)
// ------------------------------------------------------------------------
void set_signal_params(int signal, int frequency, int phase_degrees, int duty_cycle) {
    if (signal < 1 || signal > NUM_SIGNALS) {
        Serial1.println("(Teensy) Invalid signal number.");
        return;
    }
    int idx = signal - 1;

    // period in microseconds
    uint32_t period_us = 1000000UL / frequency;
    // convert period to "ticks" of 10us
    toggle_ticks[idx] = period_us / TIMER_INTERVAL_US;
    if (toggle_ticks[idx] < 1) toggle_ticks[idx] = 1;

    // compute high portion in ticks
    uint32_t tHigh = (toggle_ticks[idx] * duty_cycle) / 100;
    if (duty_cycle < 100 && tHigh > 0) {
        tHigh--;
    }
    high_ticks[idx] = tHigh;

    // phase offset in ticks
    uint32_t tPhase = (phase_degrees * toggle_ticks[idx]) / 360;
    phase_ticks[idx] = tPhase;

    Serial1.printf("(Teensy) Signal %d => freq=%d Hz, phase=%d°, duty=%d%%\n",
                  signal, frequency, phase_degrees, duty_cycle);
}
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

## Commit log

2026-08-31 Create README.md for CAD and Mechanical Design files
    Added README.md to describe CAD files structure and purpose.
2026-09-06 General Update
    [TankPCB_1-B_Cu.gbr, TankPCB_1-B_Mask.gbr, TankPCB_1-B_Paste.gbr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]
2026-09-06 Revise README for CAD and mechanical design files
    Updated README to reflect broader CAD and mechanical design files for HEartLab platform, including new file formats and general fabrication notes.
2026-09-06 Add README for CAD and mechanical design files
    This README provides details on mechanical design files for the HEartLab multimodal mapping platform, including organization, file formats, fabrication notes, and modification guidelines.
2026-09-06 Revise README for Small-Heart CAD directory
    Updated README to reflect changes in directory structure and content focus.
